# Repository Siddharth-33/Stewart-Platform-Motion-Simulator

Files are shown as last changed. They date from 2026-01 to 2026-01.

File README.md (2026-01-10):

# 🚀 Stewart Platform Motion Simulator

A real-time **3-DOF Stewart Platform Motion Simulator** controlled by an ESP32 and driven by a custom Python racing game.

This project converts **virtual game physics (roll, pitch, height)** into **physical platform motion**, creating an immersive motion simulation experience using low-cost hardware.

---

## 📌 Project Highlights

✔ Real-time serial communication between Python game and ESP32  
✔ Smooth servo motion using LEDC PWM + filtering  
✔ Custom Stewart platform geometry  
✔ Safe mechanical limits and vibration reduction  
✔ Fully open-source hardware + software  
✔ Designed for learning robotics, control systems, and embedded programming  

---

## 🎯 Motivation

Most Stewart platforms are expensive and complex.  
This project was built to:

- Learn embedded systems with ESP32  
- Understand kinematics and motion mapping  
- Connect game physics to real hardware  
- Build an affordable motion simulator using common components  
- Create a visually impressive robotics project  

---

## 🎥 Demonstration

### 🔹 Joint Motion Test  
*(Link opens video)*

[▶ Click here to view Joint Motion Test](https://github.com/user-attachments/assets/0e61225e-309b-447a-a33e-9b52f0b40c71)

---

### 🔹 Final Motion Platform Output  

[▶ Click here to view Final Working Demo](https://github.com/user-attachments/assets/d23dc95c-ccee-44ce-9eca-fbe2ea60c7e9)

---

## 📸 Final Hardware Build

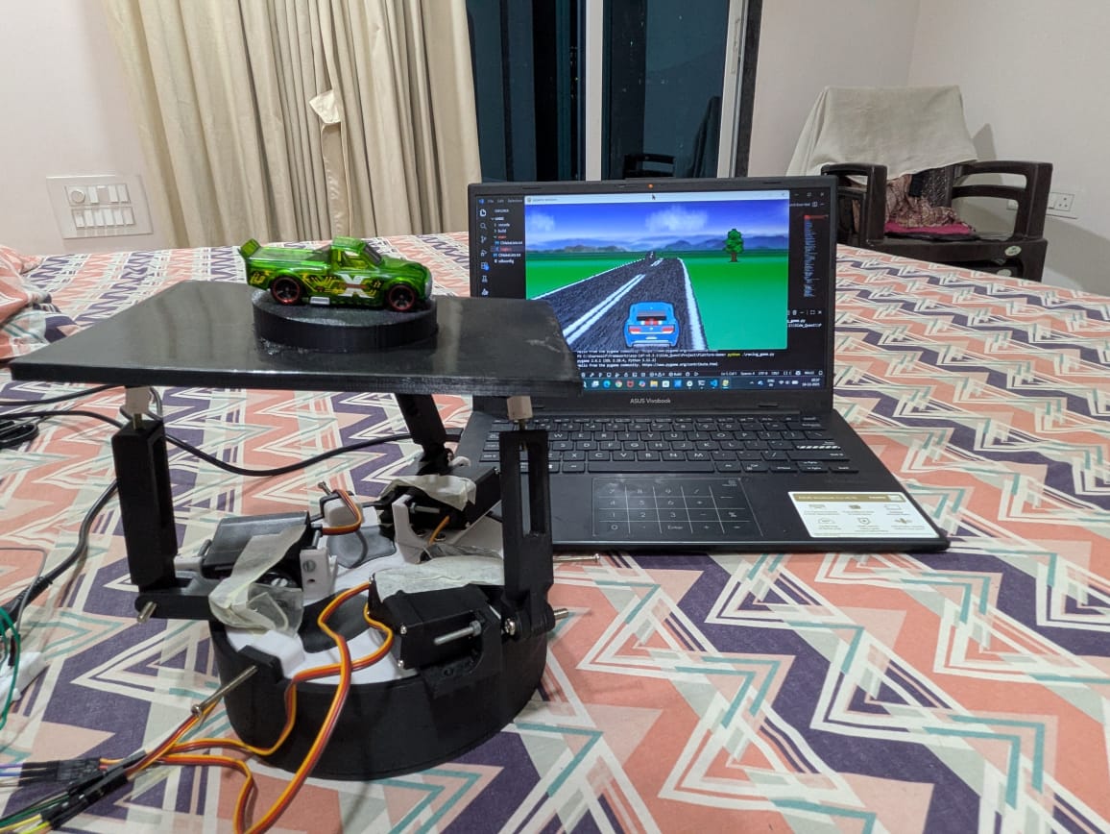
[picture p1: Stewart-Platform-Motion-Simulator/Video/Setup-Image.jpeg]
Final Platform


---

## 🧠 System Overview
Python Game (PC)
|
| Serial UART (USB)
↓
ESP32 (ESP-IDF Firmware)
|
| LEDC PWM
↓
3 × MG996R Servos
|
↓
Stewart Platform Mechanics

---

## 🎮 Python Game

The Python game is built using **pygame** and simulates:

- Road perspective rendering
- Car movement
- Trees and AI vehicles
- Terrain height variation
- Vehicle roll, pitch and height

### Output Motion Data

The game computes:

- **Roll** → Car steering angle  
- **Pitch** → Terrain slope  
- **Height** → Vertical terrain displacement  

These values are sent in real-time to ESP32:
roll,pitch,height

Example:
0.124,-0.052,0.231

---

## ⚙️ ESP32 Firmware

Written using **ESP-IDF**.

Responsibilities:

- Receive serial data
- Apply smoothing filters
- Convert motion to servo angles
- Clamp safe limits
- Generate PWM using LEDC
- Move servos smoothly without vibration

---

## 🛠 Hardware Components

| Component | Quantity |
|---|---|
| ESP32 WROOM-32 | 1 |
| MG996R Servo Motors | 3 |
| External 6V Servo Power Supply | 1 |
| Ball Joints & Linkages | Multiple |
| 3D Printed Platform Parts | Yes |
| USB Cable | 1 |

---

## 🧩 Mechanical Design

The platform uses a **3-servo triangular Stewart configuration**:

- Servos at 120° spacing
- Linkages connected to top platform
- Inverted servo mounting for mechanical advantage
- Safe angle limits applied in software

All STL files are provided in: 
Stewart-Platform-Motion-Simulator/CAD_Design

---

## 📐 Motion Mapping

Each servo contributes to platform tilt based on geometry:
Servo1 = height + rollcos(0°) + pitchsin(0°)
Servo2 = height + rollcos(120°) + pitchsin(120°)
Servo3 = height + rollcos(240°) + pitchsin(240°)

These are scaled and added to a safe center angle.

---

## 🧹 Motion Smoothing

Two smoothing layers are applied:

### 1️⃣ Low-Pass Filter

Reduces noise from game:
filtered = previous + α * (input - previous)

### 2️⃣ Slew Rate Limiter

Limits servo speed:
change ≤ MAX_SERVO_STEP per cycle

This prevents vibration and mechanical stress.

---

## 📡 Communication

| Parameter | Value |
|---|---|
| Interface | UART over USB |
| Baud Rate | 115200 |
| Data Format | ASCII CSV |
| Update Rate | ~50 Hz |

---

---

## 🚀 How to Run

### ESP32

```bash
idf.py build
idf.py flash
idf.py monitor
```
Python Game
```bash
pip install pygame pyserial
python main.py
```
---

⚠ Safety Notes
---
Always power servos from external supply

Never power MG996R from ESP32 5V

Keep mechanical angle limits strict

Start with platform unloaded

🔮 Future Improvements
---

6-DOF Stewart platform

IMU feedback

PID closed loop control

VR headset integration

Wireless communication

Larger platform

👤 Author
---
Siddharth Mishra

Electronics & Robotics Enthusiast
Stewart Platform Motion Simulator Project

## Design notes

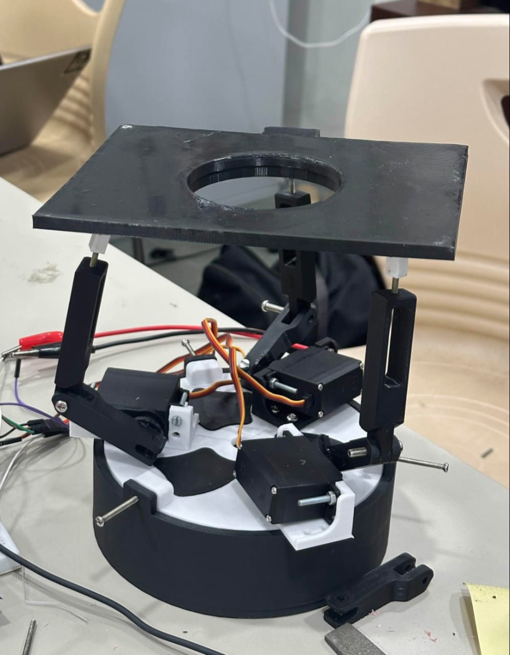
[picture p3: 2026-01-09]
Stewart-Platform-Motion-Simulator/Video/Platfom-Image.jpeg

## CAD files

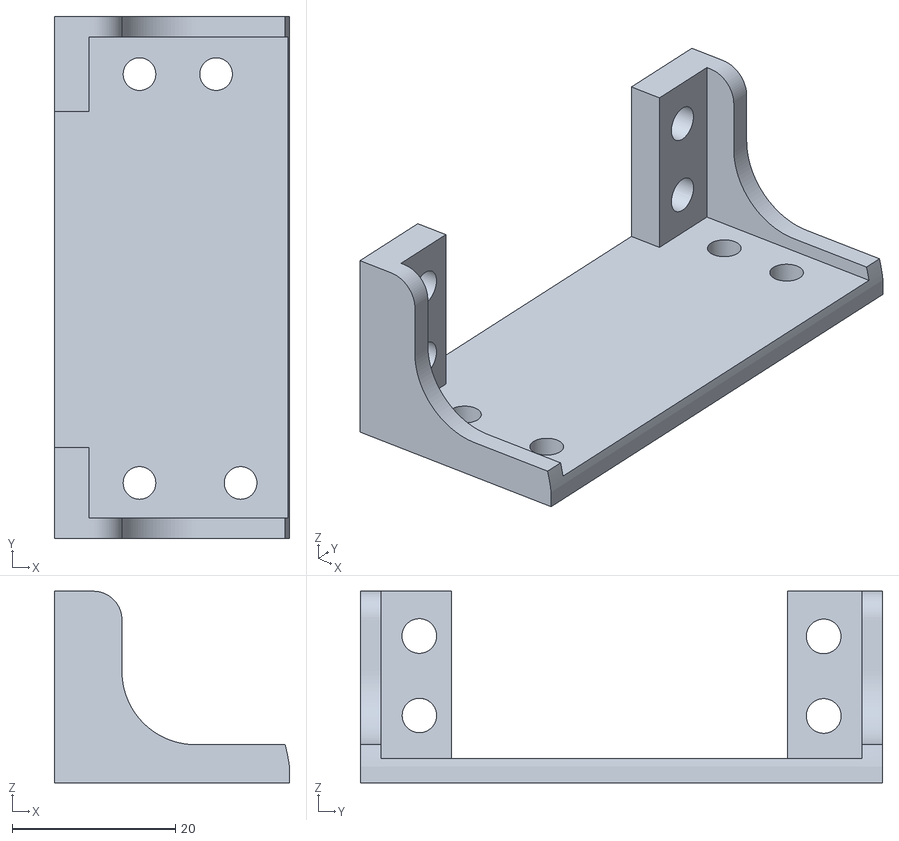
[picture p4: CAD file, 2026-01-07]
Stewart-Platform-Motion-Simulator/CAD_Design/servo_mount - Part 1.stl
28.8 x 64.0 x 23.5

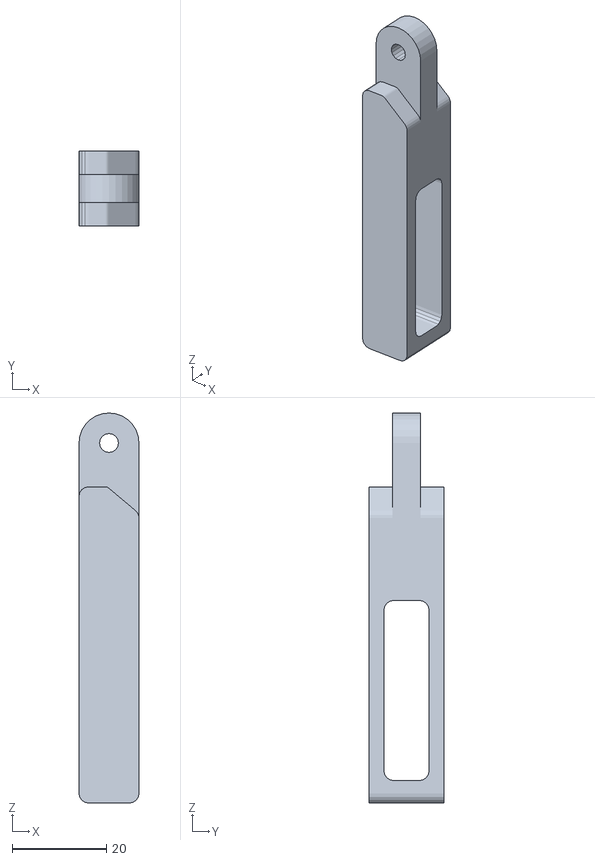
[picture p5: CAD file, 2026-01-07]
Stewart-Platform-Motion-Simulator/CAD_Design/link_#2+(x3) (1) (3) - Part 1.stl
12.7 x 15.9 x 82.5

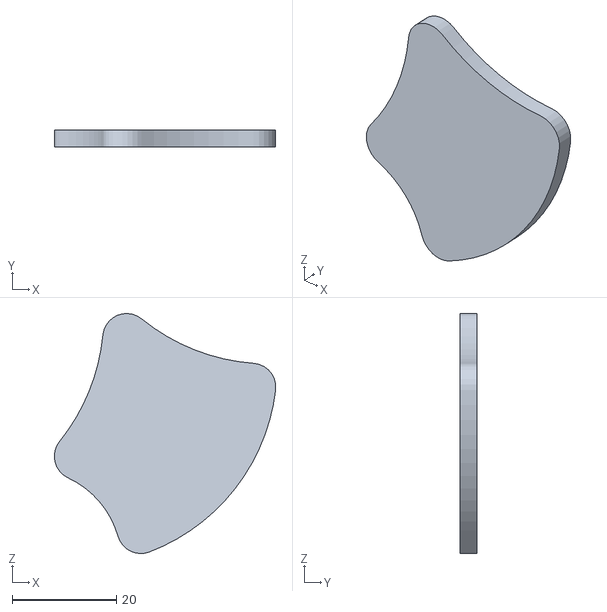
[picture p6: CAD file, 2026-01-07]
Stewart-Platform-Motion-Simulator/CAD_Design/slot_insert_1+(x3) (3) (1) - Part 1.stl
42.4 x 3.17 x 45.9

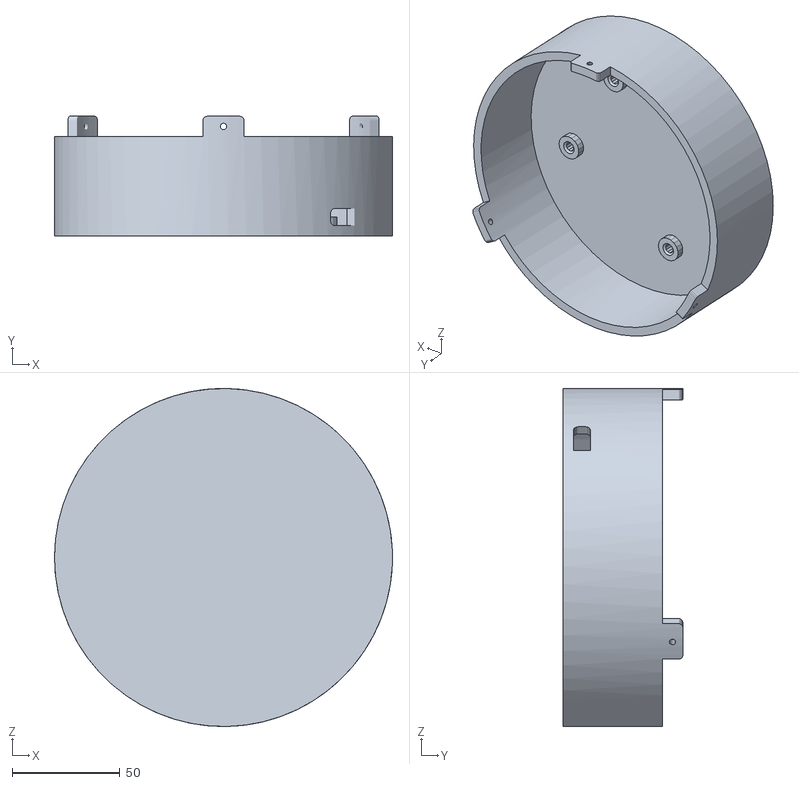
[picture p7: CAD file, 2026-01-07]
Stewart-Platform-Motion-Simulator/CAD_Design/base_stand (1) - Part 1.stl
156.9 x 55.6 x 156.9

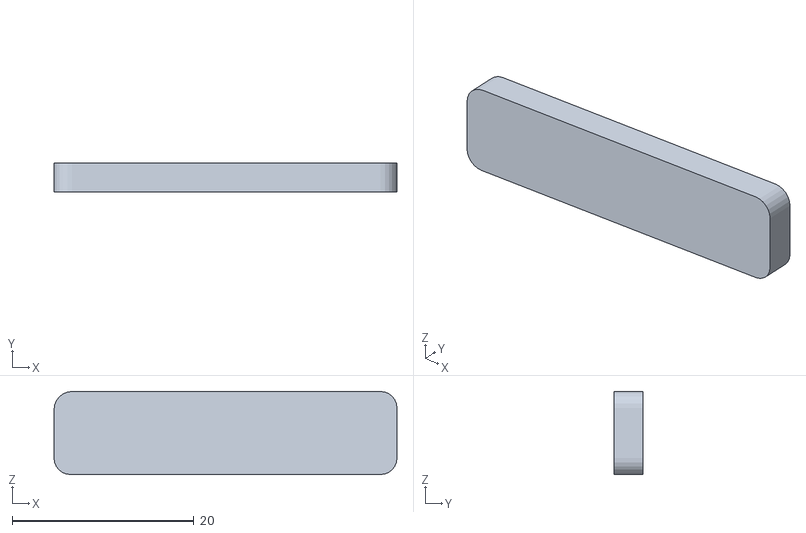
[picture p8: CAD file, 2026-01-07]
Stewart-Platform-Motion-Simulator/CAD_Design/slot_insert_2+(x3) (1) (2) - Part 1.stl
37.7 x 3.17 x 9.12

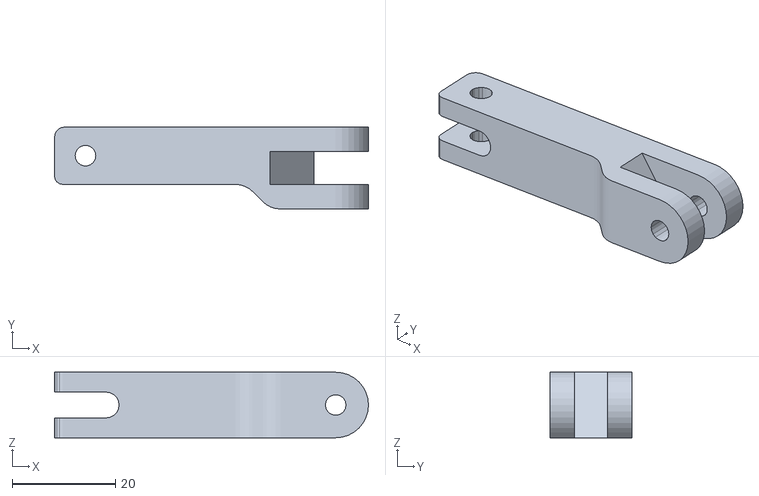
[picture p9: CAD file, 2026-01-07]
Stewart-Platform-Motion-Simulator/CAD_Design/link_#1+(x3) (1) - Part 1.stl
60.8 x 15.9 x 12.7

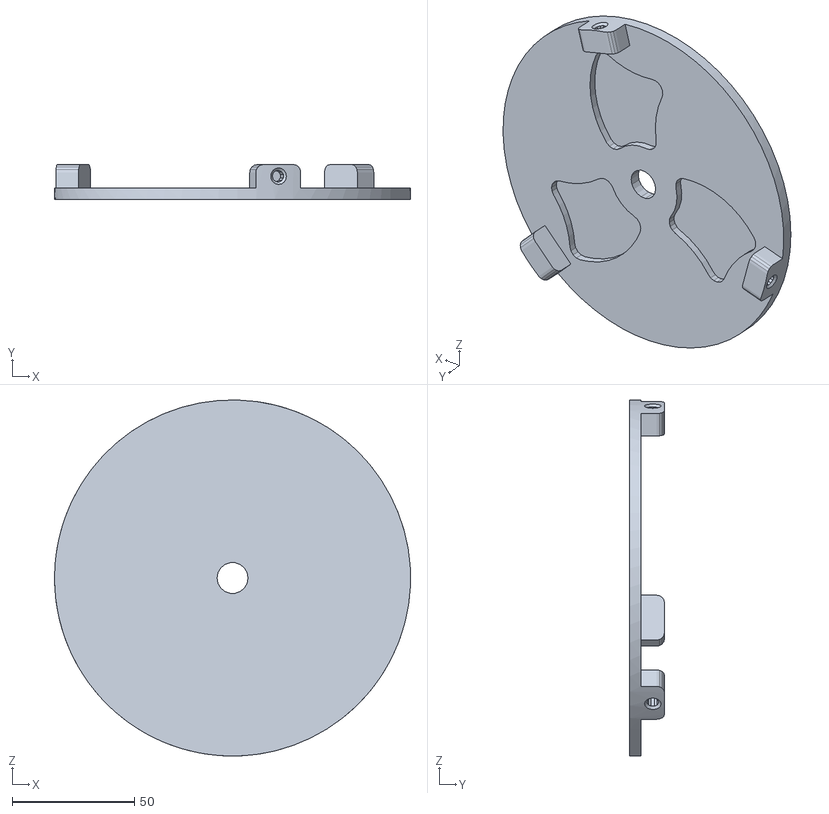
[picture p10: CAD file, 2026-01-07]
Stewart-Platform-Motion-Simulator/CAD_Design/base_plate (1) - Part 1.stl
145.8 x 14.3 x 145.8

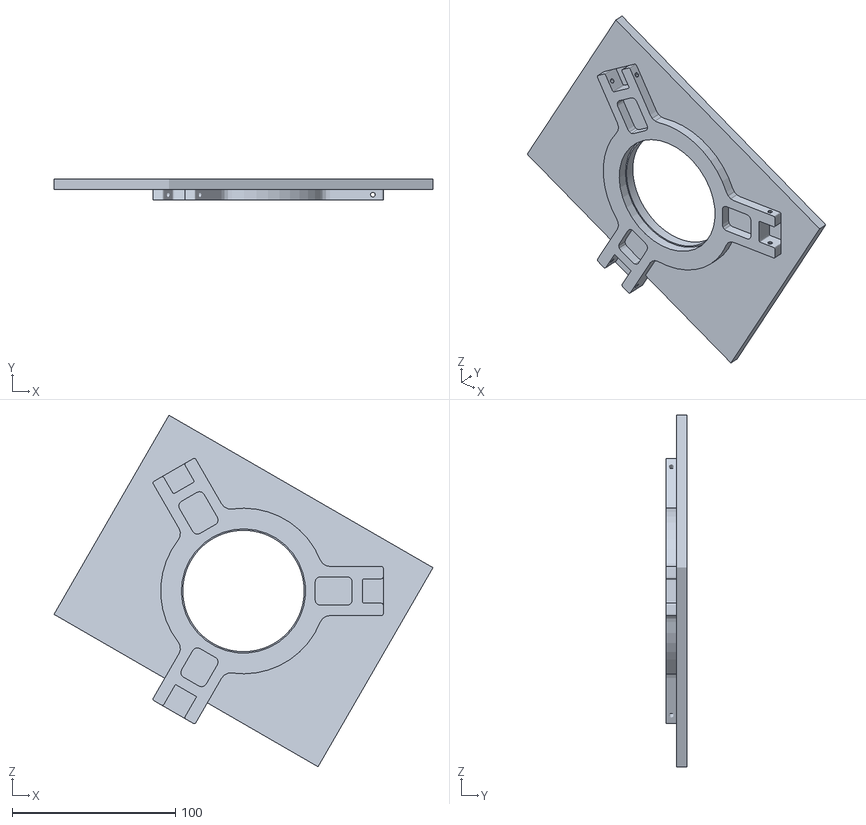
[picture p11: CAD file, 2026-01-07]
Stewart-Platform-Motion-Simulator/CAD_Design/platform_frame (1) (3) - Part 1 (1).stl
232.4 x 12.7 x 215.6

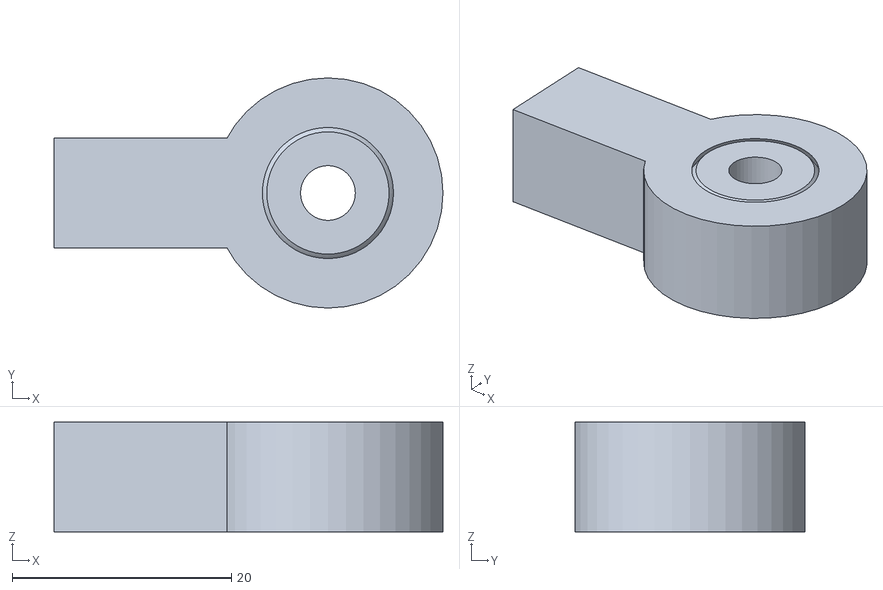
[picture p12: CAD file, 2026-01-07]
Stewart-Platform-Motion-Simulator/CAD_Design/rod_end_bearing (1).stl
35.5 x 21.0 x 10.0

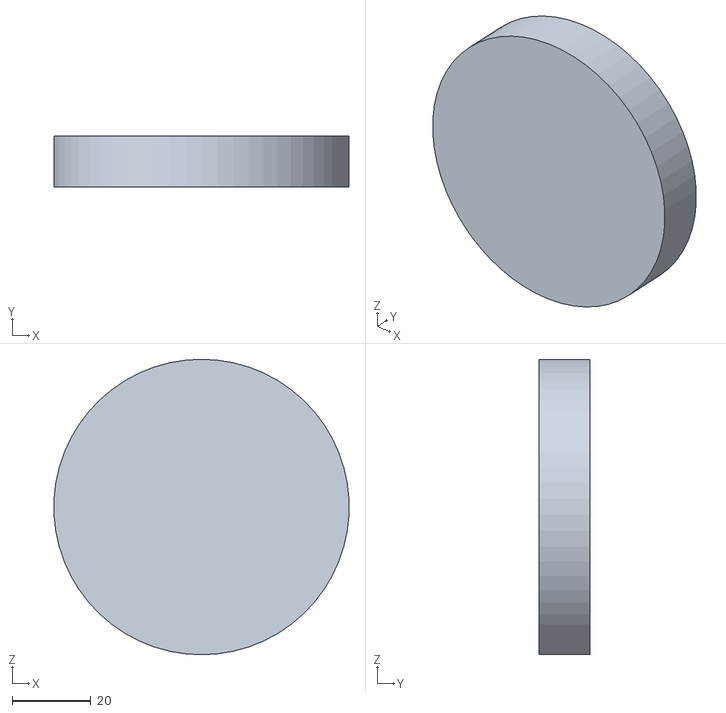
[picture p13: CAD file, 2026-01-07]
Stewart-Platform-Motion-Simulator/CAD_Design/Circle.stl
74.9 x 13.0 x 75.0

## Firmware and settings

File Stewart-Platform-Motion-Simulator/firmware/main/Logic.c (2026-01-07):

#include <stdio.h>
#include <string.h>
#include <math.h>
#include "freertos/FreeRTOS.h"
#include "freertos/task.h"
#include "driver/uart.h"
#include "driver/ledc.h"
#include "esp_log.h"

#define UART_NUM UART_NUM_0
#define BUF_SIZE 1024
#define TAG "STEWART"

// ================= SERVO GPIOs =================
#define SERVO_1_GPIO 2
#define SERVO_2_GPIO 22
#define SERVO_3_GPIO 23

// ================= LEDC CONFIG =================
#define LEDC_TIMER LEDC_TIMER_0
#define LEDC_MODE LEDC_LOW_SPEED_MODE
#define LEDC_FREQUENCY 50
#define LEDC_RESOLUTION LEDC_TIMER_13_BIT

// ================= SERVO PULSE =================
#define SERVO_MIN_PULSEWIDTH_US 500
#define SERVO_MAX_PULSEWIDTH_US 2500

#define SERVO_1_CHANNEL LEDC_CHANNEL_0
#define SERVO_2_CHANNEL LEDC_CHANNEL_1
#define SERVO_3_CHANNEL LEDC_CHANNEL_2

// ================= PLATFORM LIMITS =================
#define MAX_ROLL   40.0f
#define MAX_PITCH  40.0f
#define MAX_HEIGHT 20.0f

// ================= INVERTED SERVO RANGE =================
#define SERVO_MIN_ANGLE     0.0f
#define SERVO_MAX_ANGLE     90.0f
#define SERVO_CENTER_ANGLE  35.0f

// ================= SMOOTHING =================
#define LPF_ALPHA        0.12f   // input smoothing
#define MAX_SERVO_STEP   1.0f    // degrees per update
#define CONTROL_PERIOD_MS 20     // 50 Hz

// ================= GLOBAL STATE =================
float current_roll = 0, current_pitch = 0, current_height = 0;
float filt_roll = 0, filt_pitch = 0, filt_height = 0;

float last_s1 = SERVO_CENTER_ANGLE;
float last_s2 = SERVO_CENTER_ANGLE;
float last_s3 = SERVO_CENTER_ANGLE;

// ================= HELPERS =================
float low_pass(float prev, float input) {
    return prev + LPF_ALPHA * (input - prev);
}

float slew_limit(float prev, float target) {
    float diff = target - prev;
    if (diff > MAX_SERVO_STEP) diff = MAX_SERVO_STEP;
    if (diff < -MAX_SERVO_STEP) diff = -MAX_SERVO_STEP;
    return prev + diff;
}

// ================= ANGLE → DUTY =================
uint32_t angle_to_duty(float angle) {
    if (angle < SERVO_MIN_ANGLE) angle = SERVO_MIN_ANGLE;
    if (angle > SERVO_MAX_ANGLE) angle = SERVO_MAX_ANGLE;

    float physical_angle = 180.0f - angle;

    float pulse_width =
        SERVO_MIN_PULSEWIDTH_US +
        (physical_angle / 180.0f) *
        (SERVO_MAX_PULSEWIDTH_US - SERVO_MIN_PULSEWIDTH_US);

    return (uint32_t)((pulse_width / 20000.0f) * 8191);
}

// ================= SERVO CONTROL =================
void servo_set_angle(ledc_channel_t channel, float angle) {
    ledc_set_duty(LEDC_MODE, channel, angle_to_duty(angle));
    ledc_update_duty(LEDC_MODE, channel);
}

void servo_init(ledc_channel_t channel, int gpio) {
    ledc_channel_config_t ch = {
        .channel    = channel,
        .duty       = angle_to_duty(SERVO_CENTER_ANGLE),
        .gpio_num   = gpio,
        .speed_mode = LEDC_MODE,
        .timer_sel  = LEDC_TIMER,
        .hpoint     = 0
    };
    ledc_channel_config(&ch);
}

// ================= PLATFORM KINEMATICS =================
void calculate_platform_angles(float roll, float pitch, float height,
                               float *s1, float *s2, float *s3) {

    roll   *= MAX_ROLL;
    pitch  *= MAX_PITCH;
    height *= MAX_HEIGHT;

    float a1 = 0.0f, a2 = 120.0f, a3 = 240.0f;

    float l1 = height + roll * cosf(a1 * M_PI / 180.0f) +
                         pitch * sinf(a1 * M_PI / 180.0f);

    float l2 = height + roll * cosf(a2 * M_PI / 180.0f) +
                         pitch * sinf(a2 * M_PI / 180.0f);

    float l3 = height + roll * cosf(a3 * M_PI / 180.0f) +
                         pitch * sinf(a3 * M_PI / 180.0f);

    l1 *= 0.5f; l2 *= 0.5f; l3 *= 0.5f;

    *s1 = SERVO_CENTER_ANGLE + l1;
    *s2 = SERVO_CENTER_ANGLE + l2;
    *s3 = SERVO_CENTER_ANGLE + l3;
}

// ================= CONTROL LOOP =================
void update_platform(void) {
    float t1, t2, t3;

    calculate_platform_angles(
        current_roll, current_pitch, current_height,
        &t1, &t2, &t3
    );

    last_s1 = slew_limit(last_s1, t1);
    last_s2 = slew_limit(last_s2, t2);
    last_s3 = slew_limit(last_s3, t3);

    servo_set_angle(SERVO_1_CHANNEL, last_s1);
    servo_set_angle(SERVO_2_CHANNEL, last_s2);
    servo_set_angle(SERVO_3_CHANNEL, last_s3);
}

void control_task(void *arg) {
    while (1) {
        update_platform();
        vTaskDelay(pdMS_TO_TICKS(CONTROL_PERIOD_MS));
    }
}

// ================= UART =================
void parse_motion_data(const char *data) {
    float r, p, h;
    if (sscanf(data, "%f,%f,%f", &r, &p, &h) == 3) {
        filt_roll   = low_pass(filt_roll, r);
        filt_pitch  = low_pass(filt_pitch, p);
        filt_height = low_pass(filt_height, h);

        current_roll   = filt_roll;
        current_pitch  = filt_pitch;
        current_height = filt_height;
    }
}

void uart_rx_task(void *arg) {
    uint8_t buf[BUF_SIZE];
    char line[128];
    int pos = 0;

    while (1) {
        int len = uart_read_bytes(UART_NUM, buf, BUF_SIZE, 20 / portTICK_PERIOD_MS);
        for (int i = 0; i < len; i++) {
            if (buf[i] == '\n' || buf[i] == '\r') {
                if (pos > 0) {
                    line[pos] = '\0';
                    parse_motion_data(line);
                    pos = 0;
                }
            } else if (pos < sizeof(line) - 1) {
                line[pos++] = buf[i];
            }
        }
    }
}

// ================= MAIN =================
void app_main(void) {
    ESP_LOGI(TAG, "Smooth Stewart Platform Controller");

    uart_config_t uart_config = {
        .baud_rate = 115200,
        .data_bits = UART_DATA_8_BITS,
        .parity    = UART_PARITY_DISABLE,
        .stop_bits = UART_STOP_BITS_1,
        .flow_ctrl = UART_HW_FLOWCTRL_DISABLE,
        .source_clk = UART_SCLK_DEFAULT
    };

    uart_driver_install(UART_NUM, BUF_SIZE * 2, 0, 0, NULL, 0);
    uart_param_config(UART_NUM, &uart_config);

    ledc_timer_config_t timer = {
        .speed_mode = LEDC_MODE,
        .timer_num = LEDC_TIMER,
        .duty_resolution = LEDC_RESOLUTION,
        .freq_hz = LEDC_FREQUENCY,
        .clk_cfg = LEDC_AUTO_CLK
    };
    ledc_timer_config(&timer);

    servo_init(SERVO_1_CHANNEL, SERVO_1_GPIO);
    servo_init(SERVO_2_CHANNEL, SERVO_2_GPIO);
    servo_init(SERVO_3_CHANNEL, SERVO_3_GPIO);

    xTaskCreate(uart_rx_task, "uart_rx", 4096, NULL, 10, NULL);
    xTaskCreate(control_task, "control", 4096, NULL, 9, NULL);
}

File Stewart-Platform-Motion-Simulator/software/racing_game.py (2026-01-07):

import asyncio
import pygame as pg
import sys, math, random
import serial  # Uncomment when you connect ESP32

async def main():
    screen_size = [320, 180]
    screen = pg.display.set_mode(screen_size, pg.SCALED)
    clock = pg.time.Clock()
    

    # Initialize serial port (commented until hardware connected)
    esp = serial.Serial('COM3', 115200, timeout=1)  # Replace COM4 with your port

    road_texture = pg.image.load("assets/road.png").convert()
    mountains_texture = pg.image.load("assets/mountains.png").convert()
    car_sprite = pg.image.load("assets/car.png").convert()
    car_sprite.set_colorkey((255,0,255))
    car_sprite2 = pg.image.load("assets/car2.png").convert()
    car_sprite2.set_colorkey((255,0,255))
    tree_sprite = pg.image.load("assets/tree.png").convert()
    tree_sprite.set_colorkey((255,0,255))

    car = Player()
    cars = [Car(-50), Car(-23), Car(7)]
    trees = [Tree(-67), Tree(-55), Tree(-43), Tree(-33), Tree(-25), Tree(-13), Tree(-3)]

    running = True
    total_time = 0

    while running:
        delta = clock.tick()/1000 + 0.00001
        total_time += delta
        car.controls(delta)

        for event in pg.event.get():
            if event.type == pg.QUIT:
                running = False

        screen.blit(mountains_texture, (-65 - car.angle * 82, 0))
        vertical, draw_distance = 180, 1
        car.z = calc_z(car.x)
        z_buffer = [999 for _ in range(180)]

        while draw_distance < 120:
            last_vertical = vertical
            while vertical >= last_vertical and draw_distance < 120:
                draw_distance += draw_distance / 150
                x = car.x + draw_distance
                scale = 1 / draw_distance
                z = calc_z(x) - car.z
                vertical = int(60 + 160 * scale + z * scale)

            if draw_distance < 120:
                z_buffer[int(vertical)] = draw_distance
                road_slice = road_texture.subsurface((0, 10 * x % 360, 320, 1))
                color = (int(50 - draw_distance / 3),
                         int(130 - draw_distance),
                         int(50 - z / 20 + 30 * math.sin(x)))
                pg.draw.rect(screen, color, (0, vertical, 320, 1))
                render_element(screen, road_slice, 500 * scale, 1, scale, x, car, car.y, z_buffer)

        for index in reversed(range(len(trees) - 1)):
            scale = max(0.0001, 1 / (trees[index].x - car.x))
            render_element(screen, tree_sprite, 200 * scale, 300 * scale, scale,
                           trees[index].x, car, trees[index].y + car.y, z_buffer)

        if trees[0].x < car.x + 1:
            trees.pop(0)
            trees.append(Tree(trees[-1].x))

        for index in reversed(range(len(cars) - 1)):
            scale = max(0.0001, 1 / (cars[index].x - car.x))
            render_element(screen, car_sprite2, 100 * scale, 80 * scale, scale,
                           cars[index].x, car, -70 + car.y, z_buffer)
            cars[index].x -= 10 * delta

        if cars[0].x < car.x + 1:
            cars.pop(0)
            cars.append(Car(car.x))

        screen.blit(car_sprite, (120, 120 + math.sin(total_time * car.velocity)))

        # --- Calculate roll, pitch, height ---
        roll = car.angle
        pitch = math.sin(car.x / 10) * 0.2
        height = (calc_y(car.x) - 200) / 200

        # # # --- Send to ESP32 (commented for now) ---
        data = f"{roll:.3f},{pitch:.3f},{height:.3f}\n"
        esp.write(data.encode())

        pg.display.update()
        await asyncio.sleep(0)

class Tree:
    def __init__(self, distance):
        self.x = distance + random.randint(10, 20) + 0.5
        self.y = random.randint(500, 1500) * random.choice([-1, 1])

def calc_y(x):
    return 200 * math.sin(x / 17) + 170 * math.sin(x / 8)

def calc_z(x):
    return 200 + 80 * math.sin(x / 13) - 120 * math.sin(x / 7)

def render_element(screen, sprite, width, height, scale, x, car, y, z_buffer):
    y = calc_y(x) - y
    z = calc_z(x) - car.z
    vertical = int(60 + 160 * scale + z * scale)
    if 1 <= vertical < 180 and z_buffer[vertical - 1] > 1 / scale - 10:
        horizontal = 160 - (160 - y) * scale + car.angle * (vertical - 150)
        scaled_sprite = pg.transform.scale(sprite, (width, height))
        screen.blit(scaled_sprite, (horizontal, vertical - height + 1))

class Car:
    def __init__(self, distance):
        self.x = distance + random.randint(90, 110)


class Player:
    def __init__(self):
        self.x = 0
        self.y = 300
        self.z = 0
        self.angle = 0
        self.velocity = 0
        self.acceleration = 0

    def controls(self, delta):
        pressed = pg.key.get_pressed()
        self.acceleration += -0.5 * self.acceleration * delta
        self.velocity += -0.5 * self.velocity * delta

        if pressed[pg.K_w] or pressed[pg.K_UP]:
            self.acceleration += 4 * delta
        elif pressed[pg.K_s] or pressed[pg.K_DOWN]:
            self.acceleration -= delta

        if pressed[pg.K_a] or pressed[pg.K_LEFT]:
            self.angle -= delta * self.velocity / 10
        elif pressed[pg.K_d] or pressed[pg.K_RIGHT]:
            self.angle += delta * self.velocity / 10

        self.velocity = max(-10, min(self.velocity, 20))
        self.angle = max(-0.8, min(0.8, self.angle))
        self.velocity += self.acceleration * delta
        self.x += self.velocity * delta * math.cos(self.angle)
        self.y += self.velocity * math.sin(self.angle) * delta * 100

if __name__ == "__main__":
    pg.init()
    asyncio.run(main())
    pg.quit()
